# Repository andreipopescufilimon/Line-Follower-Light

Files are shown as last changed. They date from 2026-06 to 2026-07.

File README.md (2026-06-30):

# HyperLine Robotics Light Speed

## 🚀 About the Project

**HyperLine Robotics Light Speed** is a high-speed line follower robot developed for competitive robotics.

This robot is based on over **5 years of line follower development experience**, with a focus on speed, precision, low weight, and clean mechanical integration. Unlike many high-speed line followers, this version does **not use EDF downforce or an impeller**. Instead, the design focuses on lightweight engineering, efficient traction, custom electronics, and a compact PCB-based chassis.

The goal of this project is to achieve performance close to heavier EDF-powered robots while keeping the robot significantly lighter, simpler, and more efficient.

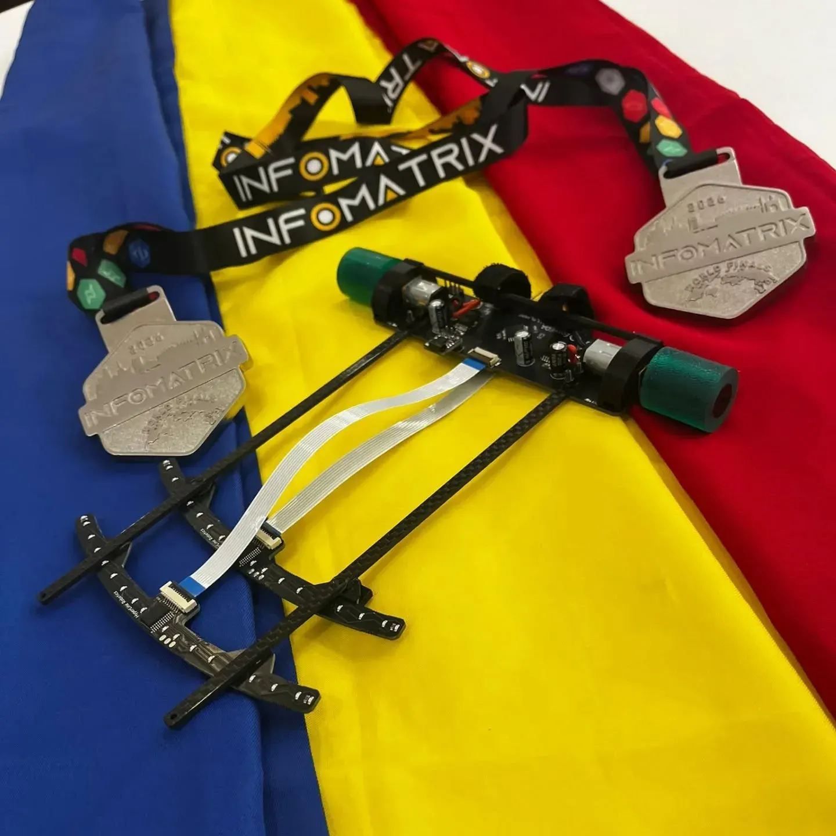
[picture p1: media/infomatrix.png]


---

## ⚡ Key Advantages

### No Additional Downforce

Many high-speed line follower robots rely on EDFs or impellers to generate downforce. Light Speed is designed to reach competitive speeds without adding artificial weight or extra power consumption.

This makes the robot lighter, more efficient, and mechanically simpler.

### Ultra-Lightweight Design

The robot weighs around **90 g**, which allows fast acceleration, sharp turns, and better agility. Every part of the robot was designed with weight reduction in mind, from the PCB chassis to the sensor connection system.

### Custom 16-Sensor Array

The robot uses a custom-designed 16-sensor array for precise line detection at high speed. The array is built to work together with our public sensor library, allowing fast calibration and reliable readings in different competition conditions.

### PCB Chassis

The main PCB also acts as the robot chassis. This reduces the need for additional structural parts, improves weight distribution, and keeps the layout compact.

### Carbon Fiber Bars and FPC Cables

The sensor board is connected using lightweight **2 mm carbon fiber bars** and **FPC cables**. This keeps the front sensor system stable while reducing unnecessary wiring and weight.

### Custom Motor Mounts and Wheels

The motor mounts and wheel rims are custom-designed and 3D printed from **ABS**. This provides good strength, low weight, and better precision for high RPM use.

---

## 🔬 Technical Details

## Lightweight Architecture

The robot was designed to be fast without relying on generated downforce. Compared with previous EDF-powered designs, this version focuses on reducing mass and improving mechanical efficiency.

Main design choices:

* Around **90 g total weight**
* Optimized component placement
* PCB chassis used as the main structure
* Lightweight front sensor support
* Silicone wheels for high grip
* Reduced vibration through motor and wheel tuning

---

## 🎯 Custom 16-Sensor Array

The sensor array is one of the most important parts of the robot. It allows the robot to detect the line with high resolution and react quickly during fast movement.

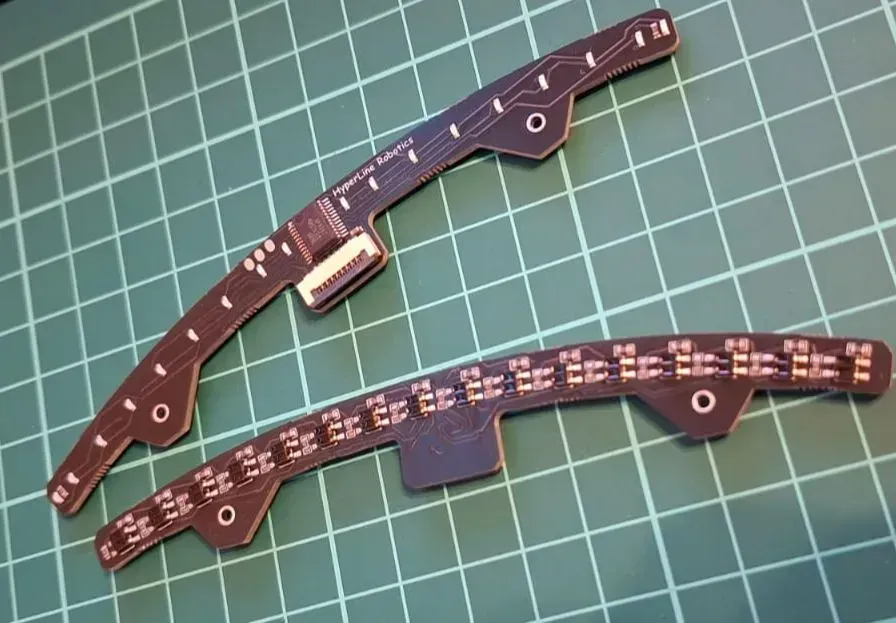
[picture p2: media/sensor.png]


Features:

* 16 individual line sensors
* Custom high-speed multiplexer integration
* Fast analog reading
* Adaptive calibration
* Designed for competition tracks
* Compatible with our public sensor library

This gives the robot accurate line position data even during aggressive acceleration, braking, and cornering.

---

## 🧩 Custom PCB Chassis

The main chassis is a custom PCB that integrates the robot electronics into one compact board.

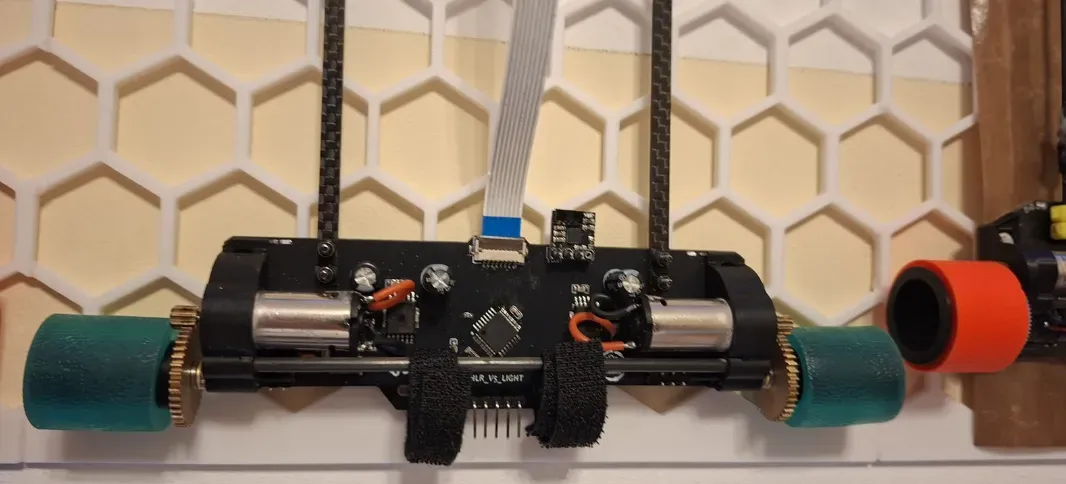
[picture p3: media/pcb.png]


It includes:

* Motor control circuitry
* Processing unit
* Sensor connectors
* Power distribution
* Compact SMD component layout
* Mounting points for mechanical parts

Using the PCB as the chassis helps reduce weight, simplifies assembly, and improves reliability.

---

## 🔧 Components and Specifications

| Component | Description |
| --- | --- |
| Custom PCB Chassis | Main structure, motor control, processing, and power distribution |
| Custom 16-Sensor Array | High-precision line detection system |
| Custom Silicone Wheels | Designed for grip, speed, and durability |
| Custom Wheel Rims | Lightweight rims designed for high RPM stability |
| Lightweight Carbon Fiber Bars | 2 mm carbon fiber bars used for sensor support |
| FPC Cables | Lightweight flexible cables used to connect the sensor board |
| Custom Motor Mounts | 3D printed using CF PLA for strength and precision |

---

## 🏆 Performance

HyperLine Robotics Light Speed was built to reach performance levels close to heavier EDF-powered line follower robots, while keeping the design lighter and more efficient.

A previous version, **HyperLine Robotics V3**, competed at the **InfoMatrix 2025 World Final**, where it won by more than **2 seconds**.

This version continues that development direction with a cleaner design, lower weight, improved electronics, and better mechanical integration.

This robot won **Robotics Championship 2026** and **InfoMatrix 2026 World Final** by a margin of almost **3-4seconds**.

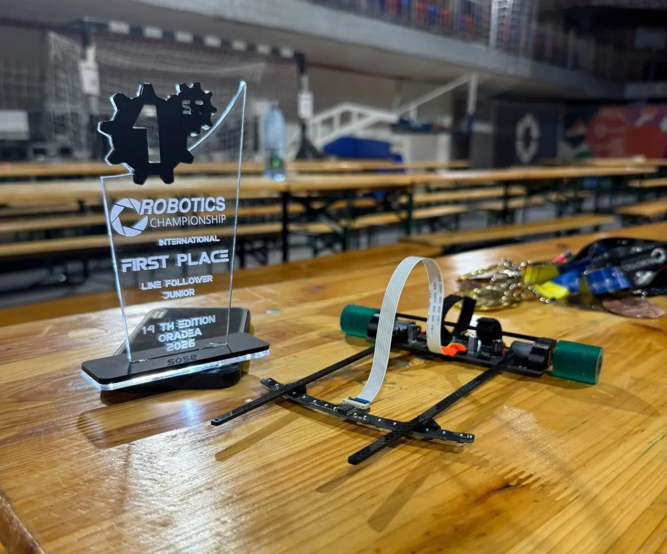
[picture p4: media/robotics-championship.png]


---

## 🎥 Media

Demonstration video: [https://www.youtube.com/watch?v=pHxVcCjtnts](https://www.youtube.com/watch?v=pHxVcCjtnts)

---

## PCB Schematic
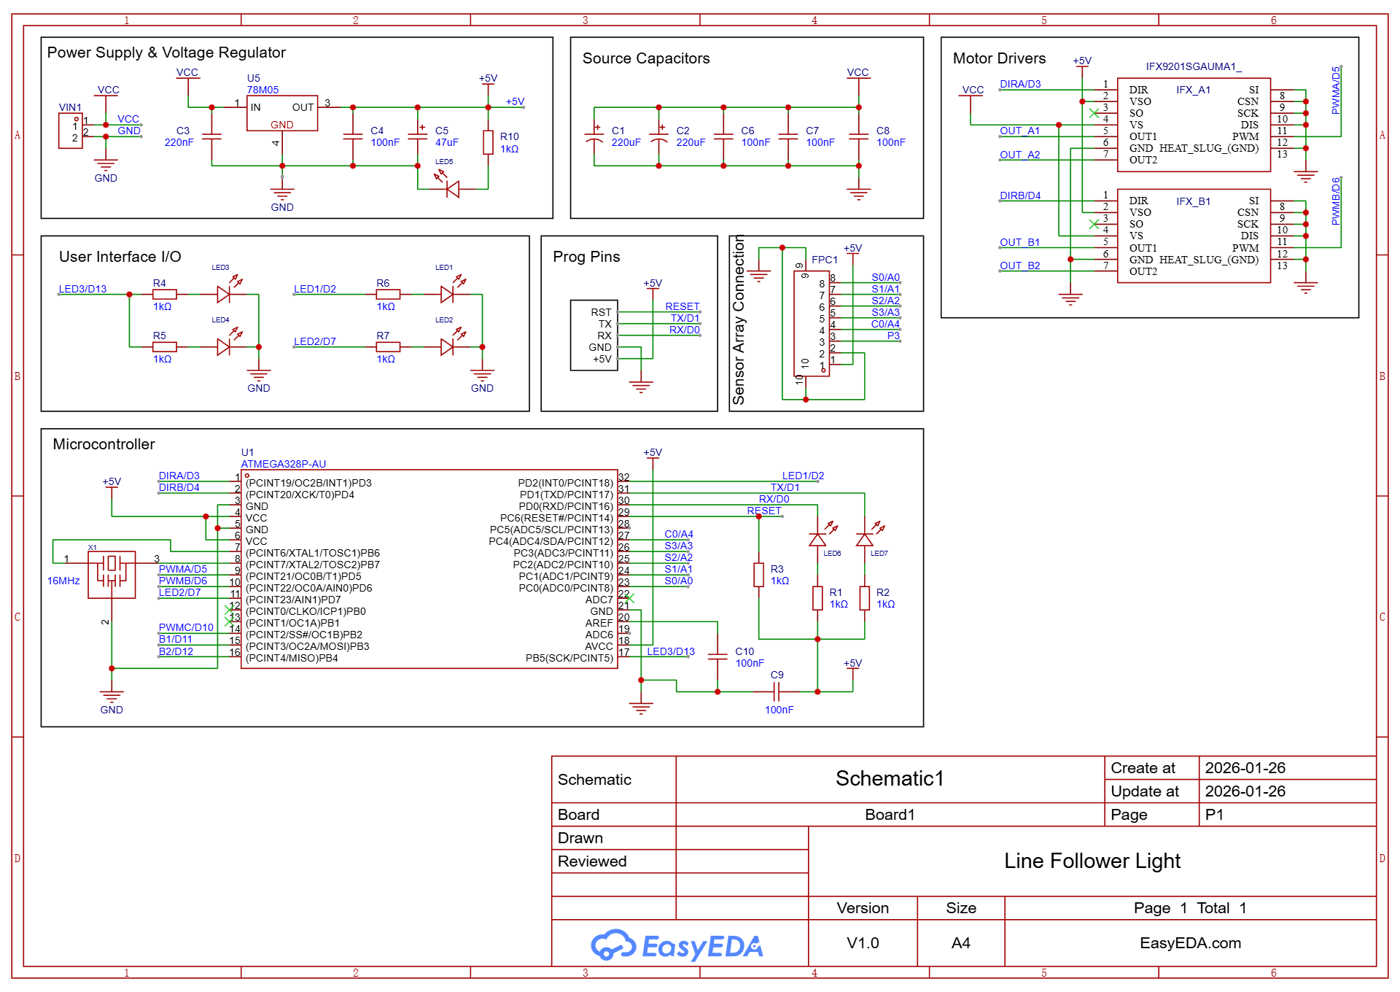
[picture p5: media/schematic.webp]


## PCB Layout
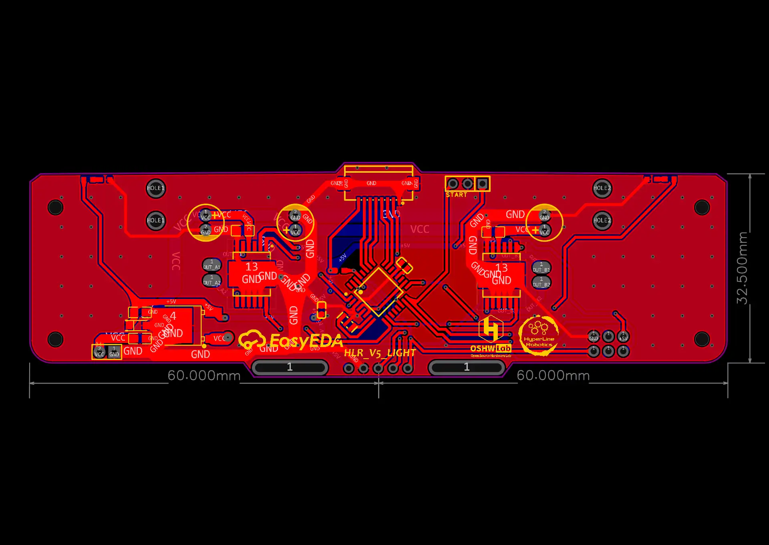
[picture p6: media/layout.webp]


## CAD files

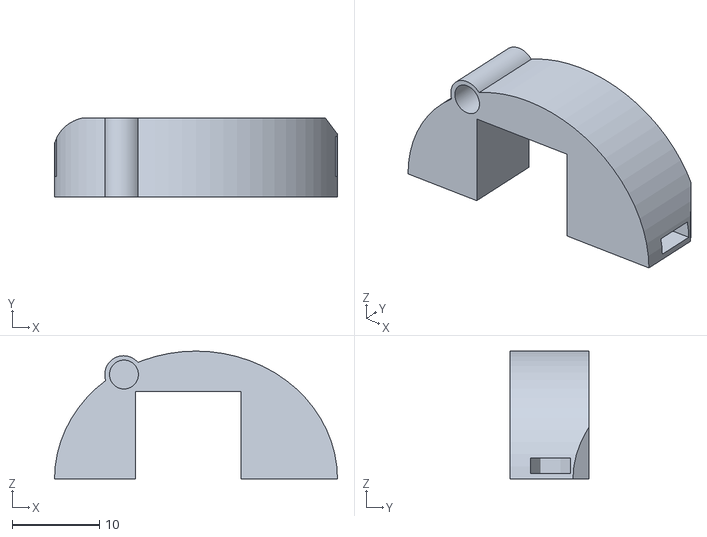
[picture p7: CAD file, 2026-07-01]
HLR_Light_Gearbox_Left.stl
32.4 x 9.00 x 14.6

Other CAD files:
HLR_Light_Gearbox_Right.stl

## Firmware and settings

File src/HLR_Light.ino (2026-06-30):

// ================================================================
//               H Y P E R L I N E   R O B O T I C S
// ================================================================
//                    FIRMWARE:  HLR_V5.1 + V3 SPEED LOGIC
//                    PLATFORM:  ATmega328P, IFX9201SG
// ================================================================

#include <Arduino.h>
#include <Servo.h>

// ================================================================
//                        PINS
// ================================================================
#define IMP_PIN 10
#define START_PIN 12

#define PWMA 5
#define DIRA 3

#define PWMB 6
#define DIRB 4

#define LED 13

#define S0 A3
#define S1 A2
#define S2 A1
#define S3 A0
#define SENSOR_OUT A4

// ================================================================
//                        SETTINGS
// ================================================================
#define NUM_SENSORS 16
#define DEBUG_MODE false

// ================================================================
//                        PID
// ================================================================
float KP = 0.03;
float KD = 0.7;

int lastError = 0;
int lastPosition = 7500;

// ================================================================
//                        SPEEDS
// ================================================================
int baseSpeed = 170;
int maxSpeed = 245;
int turnSpeed = 160;

// ================================================================
//                        EDF
// ================================================================
Servo impellerESC;

int impTarget = 1600;
int impNow = 1000;
int rampStep = 10;
int rampInterval = 20;

unsigned long lastRamp = 0;
bool impOn = false;

// ================================================================
//                        SENSORS
// ================================================================
int sensorValues[NUM_SENSORS];

// ================================================================
//                        TURN LOGIC
// ================================================================
bool turning = false;
unsigned long turnStart = 0;
const int reverseImpulseTime = 8;

// ================================================================
//        FIXED MUX SELECT FOR WIRING: S0=A3 S1=A2 S2=A1 S3=A0
// ================================================================
inline void selectMuxChannel(uint8_t ch) {
  uint8_t out = 0;

  if (ch & 0x01) out |= (1 << PC3); // S0 on A3
  if (ch & 0x02) out |= (1 << PC2); // S1 on A2
  if (ch & 0x04) out |= (1 << PC1); // S2 on A1
  if (ch & 0x08) out |= (1 << PC0); // S3 on A0

  PORTC = (PORTC & 0xF0) | out;
}

// ================================================================
//                        FAST ADC
// ================================================================
inline uint16_t fastAnalogRead(uint8_t ch) {
  ADMUX = (1 << REFS0) | (ch & 0x0F);
  ADCSRA |= (1 << ADSC);

  while (ADCSRA & (1 << ADSC));

  uint8_t low = ADCL;
  uint8_t high = ADCH;

  return (high << 8) | low;
}

// ================================================================
//                        MOTOR CONTROL
// ================================================================
void setMotorA(int pwm) {
  pwm = constrain(pwm, -255, 255);

  analogWrite(PWMA, abs(pwm));

  if (pwm > 0) {
    PORTD &= ~(1 << PORTD3);
  } else if (pwm < 0) {
    PORTD |= (1 << PORTD3);
  }
}

void setMotorB(int pwm) {
  pwm = constrain(pwm, -255, 255);

  analogWrite(PWMB, abs(pwm));

  if (pwm > 0) {
    PORTD |= (1 << PORTD4);
  } else if (pwm < 0) {
    PORTD &= ~(1 << PORTD4);
  }
}

void stopDrive() {
  setMotorA(0);
  setMotorB(0);
}

// ================================================================
//                        EDF RAMP
// ================================================================
void updateImpeller() {
  unsigned long now = millis();

  if (now - lastRamp >= (unsigned long)rampInterval) {
    lastRamp = now;

    if (impNow < impTarget) {
      impNow = min(impNow + rampStep, impTarget);
      impellerESC.writeMicroseconds(impNow);
    } else {
      impOn = true;
    }
  }
}

// ================================================================
//                        READ LINE POSITION
// ================================================================
uint16_t readLinePosition() {
  uint32_t sum = 0;
  uint32_t weightedSum = 0;

  for (uint8_t i = 0; i < NUM_SENSORS; i++) {
    selectMuxChannel(i);
    delayMicroseconds(5);

    uint16_t value = fastAnalogRead(4);

    if (value < 200) value = 0;

    sensorValues[i] = value;

    uint16_t sensorPos = (uint32_t)i * 15000UL / (NUM_SENSORS - 1);

    sum += value;
    weightedSum += (uint32_t)value * sensorPos;
  }

  if (sum == 0) {
    return lastPosition;
  }

  lastPosition = weightedSum / sum;
  return lastPosition;
}

// ================================================================
//              ADAPTIVE SPEED BASED ON LINE POSITION
// ================================================================
void updateSpeedByPosition(uint16_t position) {
  int distanceFromCenter = abs((int)position - 7500);

  if (distanceFromCenter < 1200) {
    baseSpeed = 150;
    maxSpeed = 230;
    turnSpeed = 150;
  } 
  else if (distanceFromCenter < 3000) {
    baseSpeed = 130;
    maxSpeed = 220;
    turnSpeed = 160;
  } 
  else if (distanceFromCenter < 5000) {
    baseSpeed = 80;
    maxSpeed = 190;
    turnSpeed = 150;
  } 
  else {
    baseSpeed = 45;
    maxSpeed = 180;
    turnSpeed = 130;
  }
}

// ================================================================
//                        BRAKE TURNS
// ================================================================
void turnLeftBrake() {
  updateImpeller();

  setMotorA(-turnSpeed);
  setMotorB(turnSpeed);
  delay(reverseImpulseTime);

  setMotorA(0);
  setMotorB(turnSpeed);
}

void turnRightBrake() {
  updateImpeller();

  setMotorA(turnSpeed);
  setMotorB(-turnSpeed);
  delay(reverseImpulseTime);

  setMotorA(turnSpeed);
  setMotorB(0);
}

// ================================================================
//                        SETUP
// ================================================================
void setup() {
  pinMode(PWMA, OUTPUT);
  pinMode(DIRA, OUTPUT);
  pinMode(PWMB, OUTPUT);
  pinMode(DIRB, OUTPUT);

  pinMode(START_PIN, INPUT_PULLUP);
  pinMode(LED, OUTPUT);

  DDRC |= 0x0F;

  cli();
  ADMUX = (1 << REFS0);
  ADCSRA = (1 << ADEN) | (1 << ADPS2) | (1 << ADPS1);
  sei();

  if (DEBUG_MODE) {
    Serial.begin(115200);
  }

  impellerESC.attach(IMP_PIN);
  impellerESC.writeMicroseconds(1000);

  delay(3000);

  stopDrive();

  digitalWrite(LED, HIGH);
  delay(200);
  digitalWrite(LED, LOW);
  delay(200);
  digitalWrite(LED, HIGH);

  if (DEBUG_MODE) {
    Serial.println("=== HLR_V5.1 FIXED MUX + V3 SPEED LOGIC ===");
  }
}

// ================================================================
//                        LOOP
// ================================================================
void loop() {
  bool run = digitalRead(START_PIN) == HIGH;

  if (run && !impOn) {
    updateImpeller();
    stopDrive();
    return;
  }

  if (run && impOn) {
    uint16_t position = readLinePosition();

    updateSpeedByPosition(position);

    int error = 7500 - (int)position;
    int derivative = error - lastError;
    lastError = error;

    int correction = (KP * error) + (KD * derivative);

    int leftSpeed = baseSpeed - correction;
    int rightSpeed = baseSpeed + correction;

    leftSpeed = constrain(leftSpeed, -maxSpeed, maxSpeed);
    rightSpeed = constrain(rightSpeed, -maxSpeed, maxSpeed);

    if (position <= 1000) {
      turnLeftBrake();
    } 
    else if (position >= 14000) {
      turnRightBrake();
    } 
    else {
      setMotorA(leftSpeed);
      setMotorB(rightSpeed);
    }

    if (DEBUG_MODE) {
      Serial.print("Pos: ");
      Serial.print(position);

      Serial.print("\tErr: ");
      Serial.print(error);

      Serial.print("\tBase: ");
      Serial.print(baseSpeed);

      Serial.print("\tL: ");
      Serial.print(leftSpeed);

      Serial.print("\tR: ");
      Serial.print(rightSpeed);

      Serial.print("\tSensors: ");
      for (uint8_t i = 0; i < NUM_SENSORS; i++) {
        Serial.print(sensorValues[i]);
        Serial.print(' ');
      }

      Serial.println();
    }
  } 
  else {
    if (impOn) {
      setMotorA(-80);
      setMotorB(-80);
      delay(30);

      impellerESC.writeMicroseconds(1700);
      delay(80);

      setMotorA(0);
      setMotorB(0);
      delay(20);

      impellerESC.writeMicroseconds(1000);

      impNow = 1000;
      impOn = false;
    }

    stopDrive();
  }
}
